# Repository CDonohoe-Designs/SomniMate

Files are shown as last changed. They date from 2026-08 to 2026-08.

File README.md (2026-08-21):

# SomniMate

**Pre-Obstructive Respiratory Signature Research Platform**

SomniMate is an engineering R&D project I am developing to investigate a specific question:

> **Can changes in thoracic and abdominal respiratory mechanics reveal a repeatable signature before an obstructive respiratory event?**

I am approaching the project as a hardware-first investigation. My priority is to acquire good respiratory data, understand the signal chain and test the hypothesis before making predictive claims.

The longer-term system concept is a connected wearable platform. SomniMate would act as the low-power sensing edge device, with a phone or PC client receiving data over BLE. A future mobile app could then provide the Internet gateway to an optional IoT backend for session storage, multi-night analysis and research dashboards. The app/cloud layer is intentionally deferred until the sensor chain and physiological value have been demonstrated.

> **Project status:** active research and development. The first custom RIP front-end Rev A has now progressed from hand calculation and LTspice verification into a completed Altium schematic with defined components, test points, output conditioning and filtered `3V3_AFE` supply. PCB development is the next hardware step.
>
> SomniMate is not a diagnostic medical device and is not intended for clinical use.

---

## Research concept

Thoracic and abdominal respiratory effort provide two related but independent views of breathing mechanics.

By measuring both channels together I want to investigate:

- respiratory effort amplitude
- breath-to-breath effort trends
- thorax-abdomen timing
- phase and coordination
- temporary respiratory discordance
- paradoxical movement
- waveform morphology
- changes occurring before, during and after respiratory events

I will use supporting signals such as PPG, movement, position, audio and ambient light as additional context rather than primary respiratory measurements.

I am not assuming that thoraco-abdominal paradox occurs before an obstructive event. The purpose of the project is to determine experimentally whether useful and repeatable pre-event changes are present.

---

## Development strategy

I am developing SomniMate as a staged engineering project. I first established the Nordic/Zephyr firmware and modular sensor platform, and I am now developing the respiratory-effort electronics separately so I can characterise the RIP measurement chain from first principles.

```mermaid
flowchart LR
    A["Prototype Firmware + Sensors"] --> B["Single-Channel RIP Oscillator Prototype"]
    B --> C["Characterise Respiratory Signal Chain"]
    C --> D["Dual-Channel Custom Hardware"]
    D --> E["SomniMate + SomniLink"]
    E --> F["Thorax-Abdomen Research"]
    F --> G["BLE App + IoT Integration"]
```

My immediate engineering goal is not a finished wearable or cloud platform. It is to establish a reliable single-channel respiratory-effort signal chain, understand its electrical and mechanical behaviour, and use measured results to drive the later integrated hardware.

---

## Firmware and sensor prototype

For the current development platform I am using:

- **Seeed nRF54L20A development board** — main controller and firmware platform
- **ADS1115 development board** — general analog acquisition and firmware development; no longer required in the primary RIP signal path
- **MAX30102 development board** — experimental PPG / heart-rate / SpO₂ channel
- **BH1750 development board** — ambient-light and recording-context channel
- IMU for movement and position
- microphone for acoustic / snoring investigation
- Zephyr firmware
- BLE / data logging

```mermaid
flowchart LR
    A["RIP Oscillator<br/>FREQ_OUT"] --> C["Seeed nRF54L20A<br/>Timer / Counter"]

    D["MAX30102<br/>PPG / HR"] --> C
    E["BH1750<br/>Ambient Light"] --> C
    F["IMU<br/>Motion / Position"] --> C
    G["Microphone<br/>Acoustic Context"] --> C

    C --> H["Zephyr Firmware"]
    H --> I["Sensor Acquisition"]
    H --> J["Timestamping"]
    H --> K["Signal Quality / Fault Handling"]

    I --> L["BLE / Local Data Logging"]
    J --> L
    K --> L
    L --> M["Mobile App / PC Client"]
    M --> N["Optional IoT Backend"]
    M --> O["Local Analysis"]
    N --> P["Multi-Night Analysis / Dashboard"]
```

I originally evaluated the ADS1115 as part of the respiratory acquisition path. After selecting a frequency-output RIP architecture, I no longer need an ADC in the primary RIP channel. The nRF54L20A can measure the oscillator frequency directly using a hardware timer/counter.

**[View the current firmware development](firmware/)**

---

## Custom RIP front-end prototype

For Rev A I selected a **discrete common-base Colpitts oscillator** so that RIP-belt inductance changes are represented directly as frequency changes.

The provisional model uses a 2 µH belt inductance, 2 Ω series-loss model and 1 nF / 1 nF Colpitts capacitive divider. I calculated a nominal resonance of approximately **5.03 MHz**; LTspice produced approximately **4.9 MHz** for the nominal case. Sweeping the assumed belt inductance from 1.5 µH to 2.5 µH produced approximately 5.6 MHz to 4.4 MHz, confirming the expected frequency sensitivity.

The oscillator simulation also showed that the raw resonant waveform requires conditioning before it reaches the Nordic MCU. I therefore added attenuation, Schottky limiting and a Schmitt-trigger stage to produce a clean **0–3.3 V `FREQ_RIP`** signal for direct timer/counter measurement.

The Altium Rev A schematic now implements the signal chain using an **MMBT3904LT1G** oscillator transistor, **BAT54SLT1G** Schottky clamp, **SN74LVC1G17DBVR** Schmitt buffer, a **47 Ω** series resistor on `FREQ_RIP`, explicit test points, and a filtered `3V3_AFE` rail. The AFE supply uses a simple **C-R-C / RC π-style filter** with 1 µF input capacitance, 10 Ω series isolation and 1 µF + 100 nF output decoupling, plus local 100 nF decoupling at the Schmitt buffer.

```mermaid
flowchart LR
    A["RIP Belt"] --> B["Colpitts LC Oscillator"]
    B --> C["Attenuation + Clamp Protection"]
    C --> D["Schmitt Buffer"]
    D --> E["FREQ_RIP"]
    E --> F["nRF54L20A<br/>Timer / Counter"]
```

**[View the RIP AFE design, calculations and LTspice verification →](hardware/SomniMate_RIP_AFE_Prototype/)**

---

## Intended dual-channel architecture

The later system is intended to contain two coordinated respiratory-effort modules:

- **SomniMate** — main controller and first respiratory-effort channel
- **SomniLink** — second respiratory-effort channel

```mermaid
flowchart LR
    A["Thoracic RIP Strap"] --> B["SomniMate<br/>RIP Oscillator"]
    C["Abdominal RIP Strap"] --> D["SomniLink<br/>RIP Oscillator"]

    D --> E["Inter-Module Link"]
    B --> F["SomniMate<br/>Main Controller"]
    E --> F

    G["PPG"] --> F
    H["IMU"] --> F
    I["Microphone"] --> F

    F --> J["Synchronized Acquisition"]
    J --> K["BLE / Logging"]
    J --> L["Signal Processing"]

    L --> M["Thorax-Abdomen<br/>Phase / Coordination"]
    L --> N["Breath-by-Breath<br/>Effort Features"]
    M --> O["Pre-Event Investigation"]
    N --> O
```

I have intentionally not fixed the eventual SomniLink-to-SomniMate interface yet. Synchronization, signal quality, size and power will drive that decision.

---

## Planned connected system architecture

SomniMate is intended to become the edge node of a connected monitoring platform without requiring Wi-Fi or cellular hardware in the wearable itself.

```mermaid
flowchart LR
    A["SomniMate + SomniLink<br/>Respiratory Sensing"] --> B["SomniMate<br/>nRF54 + Zephyr"]
    B -->|"BLE"| C["SomniMate Mobile App"]
    C -->|"Wi-Fi / Cellular"| D["Optional IoT Backend"]
    C --> E["Local Session Review"]
    D --> F["Session Storage"]
    D --> G["Multi-Night Trends"]
    D --> H["Research Dashboard"]
```

The intended division of responsibility is:

- **SomniMate wearable** — sensor acquisition, timestamping, signal-quality checks, local buffering and BLE communication.
- **Mobile app / PC client** — pairing, device status, recording control, data transfer, basic visualization and acting as the Internet gateway.
- **IoT backend** — optional later layer for synchronized session storage, multi-night analysis, algorithm development and remote research dashboards.

This keeps the body-worn hardware focused on sensing, synchronization and low-power BLE while allowing Internet connectivity to evolve independently. No app, cloud service or remote monitoring claim is part of the current hardware proof of concept.

**[View the connected IoT architecture →](docs/CONNECTED_IOT_ARCHITECTURE.md)**

---

## Wearable concept

My current mechanical concept uses separate thoracic and abdominal effort straps with a centrally mounted controller. It is an early development concept intended to explore sensor placement, cable routing and wearable integration rather than final industrial design.

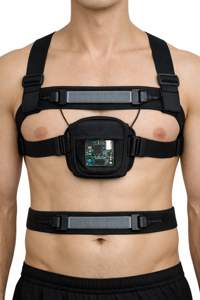
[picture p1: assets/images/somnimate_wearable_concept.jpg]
SomniMate wearable concept


**[View image in assets](assets/images/somnimate_wearable_concept.jpg)**

---

## Supporting sensors

### MAX30102

I am using the MAX30102 experimentally for:

- PPG waveform acquisition
- heart rate
- pulse amplitude changes
- experimental SpO₂ investigation

I am treating SpO₂ as experimental until the complete optical implementation and measurement method have been validated.

### IMU

I am using the IMU to investigate:

- body position
- posture changes
- movement detection
- motion artefacts

### Microphone

I am using the microphone experimentally for:

- snoring
- airway acoustic activity
- respiratory-event context

### BH1750

I added the BH1750 as a contextual sensor rather than a primary respiratory sensor. It can provide ambient-light level, lights-on / lights-off transitions and additional timestamped context during recordings while also giving me another useful I²C peripheral during firmware development.

---

## Development status

### Firmware and modular sensors

- [x] Core research question defined
- [x] Nordic / Zephyr environment established
- [x] Initial firmware bring-up
- [x] I²C communication established
- [x] ADS1115 evaluated
- [x] MAX30102 evaluated
- [x] Integrate ADS1115 and MAX30102 into common application
- [x] Add BH1750
- [x] Integrate IMU
- [x] Integrate microphone
- [ ] Implement synchronized timestamping
- [ ] Implement structured data logging
- [ ] Add RIP frequency measurement using Nordic timer/counter

### RIP front end

- [x] Create dedicated Altium RIP prototype project
- [x] Establish schematic / PCB / library / output project structure
- [x] Define Rev-A design criteria
- [x] Compare discrete and dedicated inductance-conversion architectures
- [x] Select discrete Colpitts oscillator for Rev A
- [x] Establish provisional 2 µH belt model
- [x] Calculate nominal LC resonance
- [x] Select and bias 3904-family oscillator device
- [x] Build LTspice oscillator model
- [x] Run RIP inductance sweep
- [x] Evaluate belt series-resistance / Q sensitivity
- [x] Add attenuation and Schmitt-trigger output conditioning
- [x] Verify clean 0–3.3 V `FREQ_RIP` output in LTspice
- [x] Add and simulate `3V3_AFE` RC π-style supply filter
- [x] Select real Rev A parts for Q1, D1 and U1
- [x] Add prototype test points
- [x] Complete the Rev A Altium schematic
- [x] Generate the Rev A schematic PDF output
- [ ] Design the prototype PCB
- [ ] Assemble and bring up the prototype
- [ ] Characterise actual belt inductance / sensitivity / losses
- [ ] Capture controlled respiratory waveforms

### Dual-channel SomniMate / SomniLink hardware

- [ ] Convert measured single-channel results into the dual-channel architecture
- [ ] Design SomniMate controller hardware
- [ ] Design SomniLink hardware
- [ ] Define inter-module communication
- [ ] Build and bring up custom PCBs
- [ ] Verify synchronized thoracic / abdominal operation
- [ ] Evaluate wearable implementation
- [ ] Begin overnight dual-channel data collection
- [ ] Perform thoraco-abdominal phase / coordination analysis

### Connected app / IoT layer — later phase

- [ ] Define BLE GATT services and structured session-data format
- [ ] Prototype SomniMate mobile app or PC client
- [ ] Implement device status, recording control and data transfer over BLE
- [ ] Define secure app-to-backend session upload
- [ ] Prototype optional IoT session storage
- [ ] Add multi-night trend and research-dashboard capability

---

**SomniMate is an independent research and engineering project. It is not a diagnostic or therapeutic medical device.**

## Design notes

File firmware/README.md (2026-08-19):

# Firmware Development

This folder contains the staged Zephyr / nRF Connect SDK bring-up work used during Phase 1 of SomniMate.

The examples are intentionally kept small so that each interface can be verified independently before moving to the next stage.

## Bring-up sequence

1. **01_ADS1115_Bringup** — basic I²C communication with the ADS1115 and configuration-register readback.
2. **02_MAX30102_Bringup** — basic I²C communication with the MAX30102 and Part ID verification.
3. **03_ADS1115_MAX30102** — confirms that the ADS1115 and MAX30102 operate together on the same I²C bus.
4. **04_ADS1115_Potentiometer** — configures ADS1115 AIN3 for single-ended conversion and verifies analogue voltage measurement using a potentiometer.
5. **05_BH1750_Bringup** — reads ambient-light level from a GY-302 / BH1750 sensor in continuous high-resolution mode.
6. **06_ADS1115_MAX30102_BH1750** — confirms that the ADS1115, MAX30102 and BH1750 can operate together on the same I²C bus.

Current bring-up platform: **Nordic nRF5340 DK** with **Zephyr / nRF Connect SDK**.

The nRF5340 DK is being used as the initial firmware-learning and sensor-integration platform before moving the prototype to the planned nRF54L20A hardware.

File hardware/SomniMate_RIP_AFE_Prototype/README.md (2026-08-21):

# SomniMate RIP AFE Prototype

**Rev A — Discrete Colpitts respiratory-inductance front end**

This folder is the engineering record for the first custom SomniMate respiratory inductance plethysmography (RIP) front end.

I am using a hardware-first approach: define the sensing requirement, calculate a starting circuit, verify it in LTspice, document the assumptions and then carry the verified design into Altium for PCB development.

> **Status:** Rev A oscillator, output conditioning and `3V3_AFE` supply filtering have been verified in LTspice and transferred into a completed Altium schematic. PCB development is the next step.
>
> This is a non-clinical R&D prototype, not a diagnostic or therapeutic medical device.

---

## Design objective

For Rev A I am deliberately developing **one RIP channel** before duplicating the architecture for synchronized thoracic and abdominal measurements.

My design priorities are:

- small physical size
- low power consumption
- 3.3 V operation
- low component count and BOM cost
- direct interface to an nRF54L20A timer/counter
- relative respiratory-effort measurement rather than calibrated lung-volume measurement
- simple duplication for a second channel
- testability and accessible signal nodes
- tolerance of belt-to-belt electrical variation
- low-voltage battery-powered wearable operation

The current signal chain is:

```mermaid
flowchart LR
    A["RIP Belt"] --> B["Colpitts LC Oscillator"]
    B --> C["Attenuation + Clamp Protection"]
    C --> D["Schmitt Buffer"]
    D --> E["FREQ_RIP"]
    E --> F["nRF54L20A Timer / Counter"]
    F --> G["Relative Respiratory Effort"]
```

I chose a frequency-output architecture rather than producing an analog respiratory voltage. This removes the need for an ADC, conventional anti-alias filter and unity-gain op-amp buffer in the primary RIP path.

---

## Architecture choice

I considered four approaches:

1. discrete LC oscillator with MCU frequency measurement
2. dedicated inductance-to-digital conversion, including the TI LDC1612
3. oscillator followed by frequency-to-voltage conversion and ADC
4. synchronous analog excitation/demodulation

For Rev A I selected a **common-base Colpitts oscillator**.

I chose the discrete approach because it keeps the sensing mechanism visible, is compact and low power, and gives me direct control over excitation, loading and output conditioning. It also lets me characterize the unknown RIP-belt electrical behaviour before considering a more integrated converter.

The TI LDC1612 remains a credible later alternative, particularly because one device could potentially support two inductive channels.

---

## Rev A starting model

I do not yet have measured LCR data for the physical RIP belt, so the belt values below are explicitly **provisional modelling assumptions**.

| Parameter | Rev A value |
|---|---:|
| Supply | 3.3 V |
| Q1 hardware | MMBT3904LT1G |
| R1 | 47 kΩ |
| R2 | 18 kΩ |
| R3 | 470 Ω |
| Belt series resistance model | 2 Ω nominal |
| RIP inductance | 2 µH nominal |
| Inductance sweep | 1.5–2.5 µH |
| C1 | 1 nF |
| C2 | 1 nF |
| C3 | 100 nF |
| C4 | 10 nF |
| Output divider R5/R6 | 10 kΩ / 10 kΩ |
| Output clamp | BAT54SLT1G |
| Schmitt buffer | SN74LVC1G17DBVR |
| Output series resistor R7 | 47 Ω |
| Supply filter | 1 µF / 10 Ω / 1 µF + 100 nF |
| U1 local decoupling | 100 nF |

For the Colpitts divider:

```text
Ceq = (C1 × C2) / (C1 + C2)
    = (1 nF × 1 nF) / (1 nF + 1 nF)
    = 500 pF
```

Using the provisional 2 µH belt value:

```text
f0 = 1 / (2π√(LC))
   ≈ 5.03 MHz
```

This was my first-order design target before simulation.

---

## LTspice verification

### 1. Oscillator implementation

I built the Rev A common-base Colpitts model in LTspice and annotated the circuit with the assumptions and key design intent.

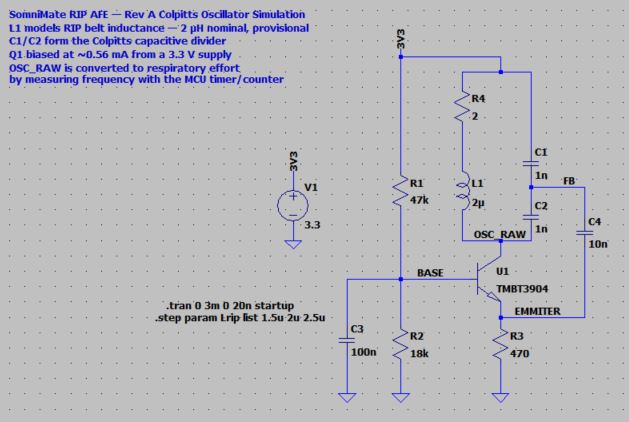
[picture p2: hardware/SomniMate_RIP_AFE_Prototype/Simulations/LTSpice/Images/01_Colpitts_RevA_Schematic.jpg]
Rev A Colpitts schematic


### 2. RIP inductance sensitivity

I swept the provisional RIP-belt inductance using:

```text
.step param Lrip list 1.5u 2u 2.5u
```

The result confirms the expected monotonic relationship: increasing inductance lowers the oscillator frequency.

| Assumed RIP inductance | Ideal calculation | Approx. LTspice result |
|---:|---:|---:|
| 1.5 µH | 5.81 MHz | ~5.6 MHz |
| 2.0 µH | 5.03 MHz | ~4.9 MHz |
| 2.5 µH | 4.50 MHz | ~4.4 MHz |

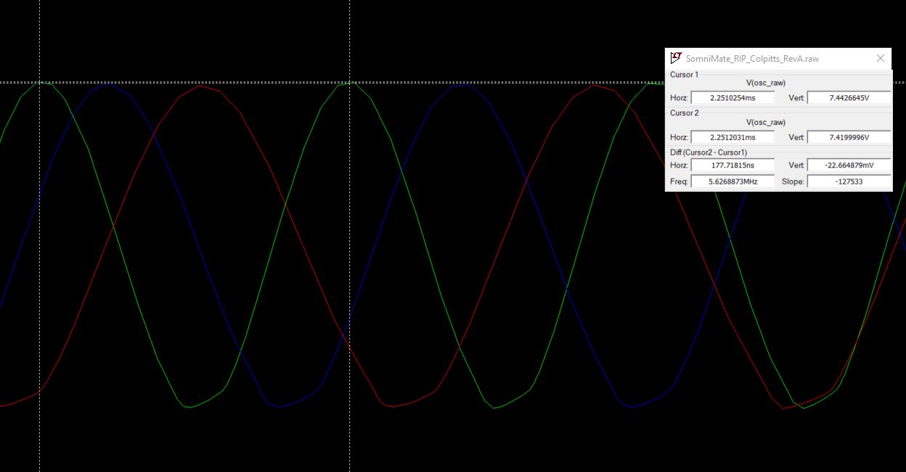
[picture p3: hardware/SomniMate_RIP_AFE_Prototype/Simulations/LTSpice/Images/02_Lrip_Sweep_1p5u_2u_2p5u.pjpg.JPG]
RIP inductance sweep


The small difference between the ideal calculation and simulated result is expected because the hand calculation treats the tank as ideal while the LTspice circuit includes transistor loading and parasitic behaviour.

### 3. Bias and power

The LTspice operating-point analysis gave approximately:

- base voltage: **0.864 V**
- emitter voltage: **0.263 V**
- emitter current: **0.559 mA**
- total supply current: **0.607 mA**

At 3.3 V this corresponds to approximately:

```text
P ≈ 3.3 V × 0.607 mA ≈ 2.0 mW
```

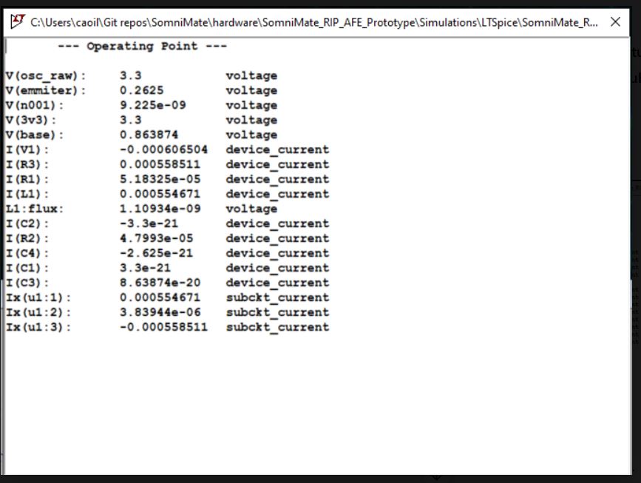
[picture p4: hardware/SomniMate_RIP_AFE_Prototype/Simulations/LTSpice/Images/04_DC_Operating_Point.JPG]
DC operating point


This is a useful first-pass result for a battery-powered wearable sensor channel. I have not yet attempted to optimize the oscillator below this current.

### 4. Belt-loss / Q sensitivity

A real RIP belt is not an ideal inductor. I therefore added a series-resistance model and investigated increasing resonator loss.

The current Rev A topology has strong oscillation margin around the provisional **2 Ω** case, while 5–10 Ω produces substantially reduced amplitude.

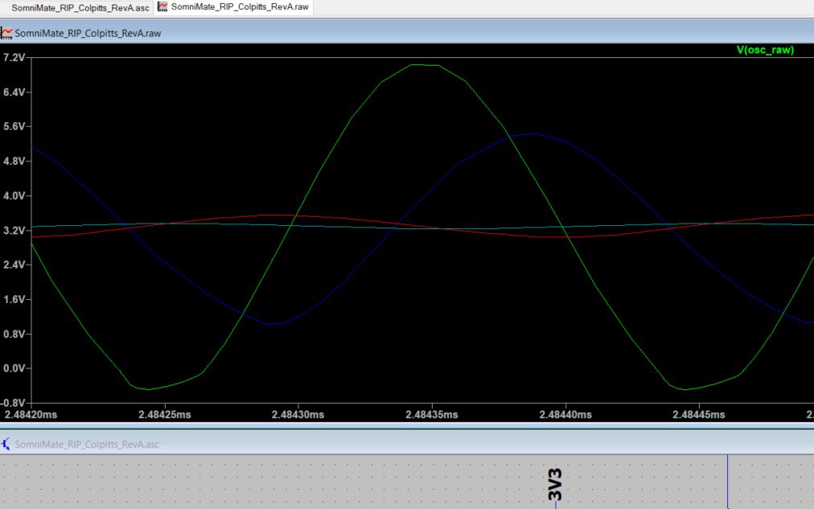
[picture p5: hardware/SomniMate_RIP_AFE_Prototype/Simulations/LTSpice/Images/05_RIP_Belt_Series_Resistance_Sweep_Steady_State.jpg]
RIP belt series resistance sweep


---

## Output conditioning

The oscillator simulation also exposed an important interface requirement: the raw resonant waveform is not a safe MCU logic signal.

I therefore added:

- a **10 kΩ / 10 kΩ divider** to attenuate `OSC_RAW`
- a **BAT54SLT1G dual Schottky clamp** around the buffer input
- an **SN74LVC1G17DBVR Schmitt-trigger buffer** to convert the sine-like waveform into a clean 0–3.3 V digital signal
- a **47 Ω series resistor** on `FREQ_RIP`

The LTspice model uses the generic behavioral `schmtbuf` device to verify the transfer concept; the Altium implementation uses the selected hardware part.

### Final attenuated, protected and buffered Rev A schematic

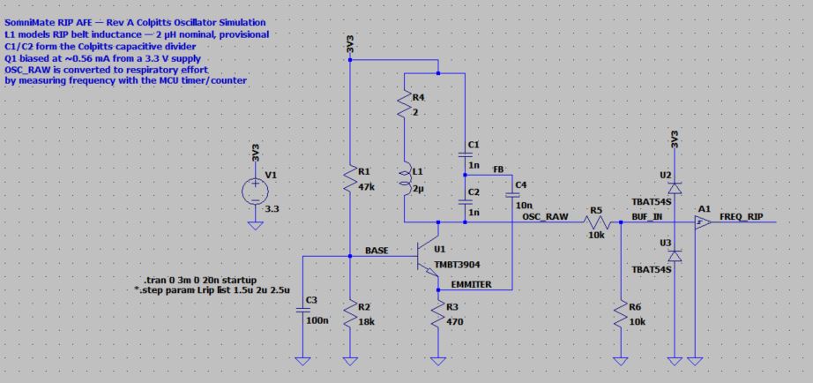
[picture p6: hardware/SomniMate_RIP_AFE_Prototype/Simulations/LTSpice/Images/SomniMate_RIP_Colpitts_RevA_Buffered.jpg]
Buffered Rev A Colpitts schematic


### Raw oscillator waveform

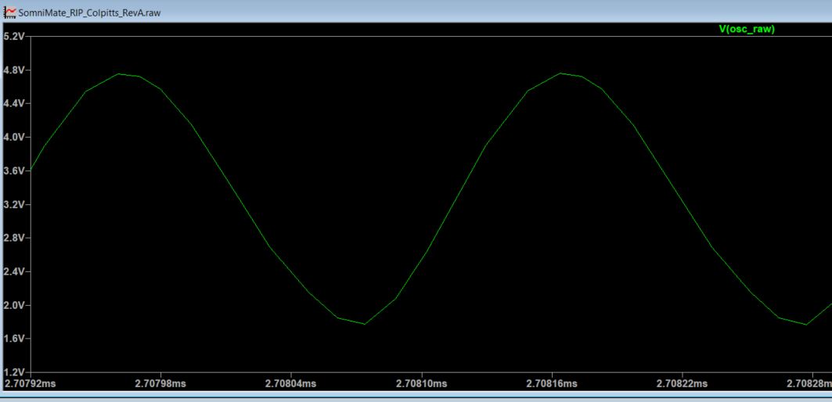
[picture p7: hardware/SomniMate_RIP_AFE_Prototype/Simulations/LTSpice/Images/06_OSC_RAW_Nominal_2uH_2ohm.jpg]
OSC RAW


### Attenuated / protected buffer input

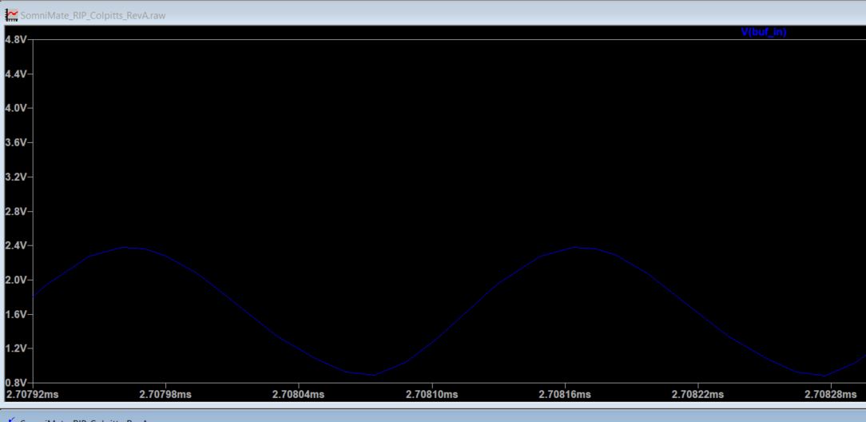
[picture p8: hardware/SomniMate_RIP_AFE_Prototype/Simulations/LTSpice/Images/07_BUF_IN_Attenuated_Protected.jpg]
Buffer input


### Schmitt output

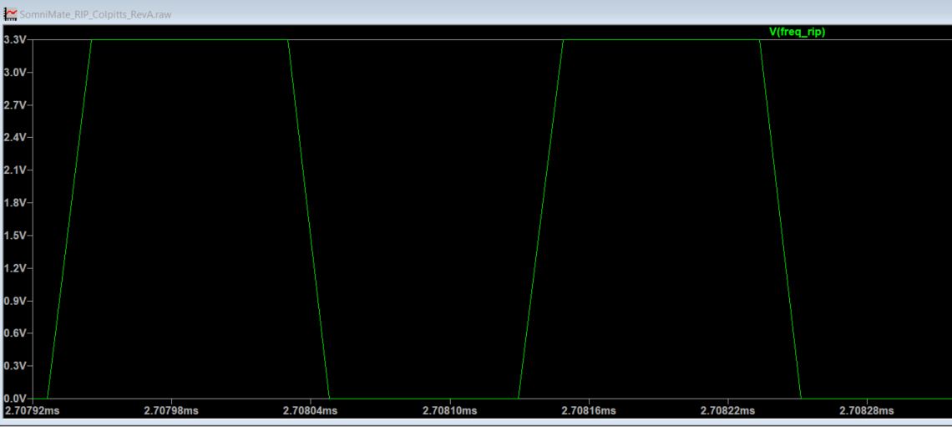
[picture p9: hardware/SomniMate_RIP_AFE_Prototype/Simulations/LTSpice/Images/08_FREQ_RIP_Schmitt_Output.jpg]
FREQ RIP


### Complete signal conversion

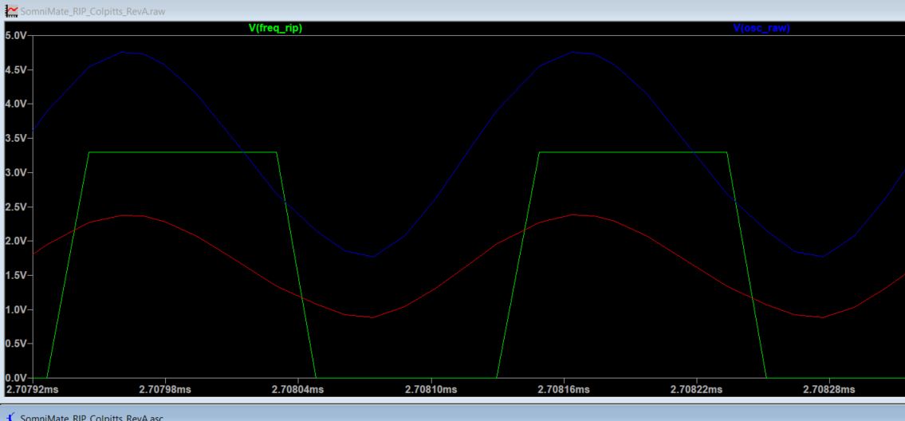
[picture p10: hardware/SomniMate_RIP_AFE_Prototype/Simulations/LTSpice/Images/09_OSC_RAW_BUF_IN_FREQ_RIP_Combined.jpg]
OSC RAW, BUF IN and FREQ RIP


---

## 3V3_AFE supply filtering

I added a simple **C-R-C / RC π-style supply filter** between the main 3.3 V rail and the sensitive RIP AFE supply.

The implemented network is:

```text
3V3 ----+---- R8 10Ω ----+---- 3V3_AFE
        |                |
      C5 1µF           C6 1µF
        |                |
       GND             C7 100nF
                         |
                        GND
```

C6 and C7 are electrically in parallel. A separate **C8 = 100 nF** is placed locally at the SN74LVC1G17 supply pins.

The purpose is to reduce supply-borne digital noise reaching the oscillator and to provide impedance isolation between the AFE and the main 3.3 V rail. It is not galvanic isolation.

I modelled the filter separately in LTspice using a simplified 0.5 Ω source/interconnect impedance and an AC sweep from 10 Hz to 500 MHz.

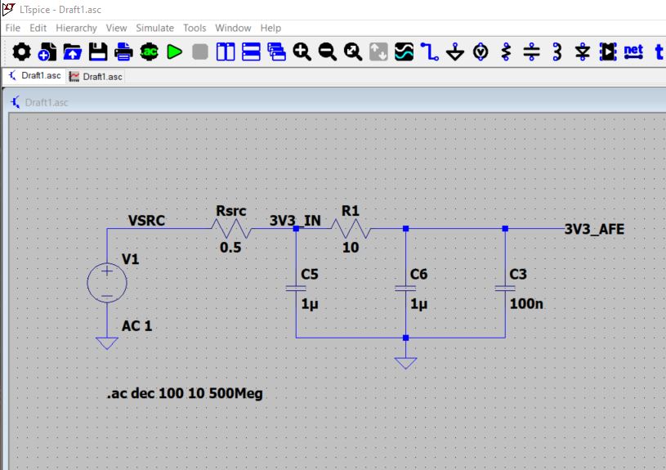
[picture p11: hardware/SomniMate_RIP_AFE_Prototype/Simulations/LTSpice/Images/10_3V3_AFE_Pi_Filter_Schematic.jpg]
3V3 AFE pi-style filter schematic


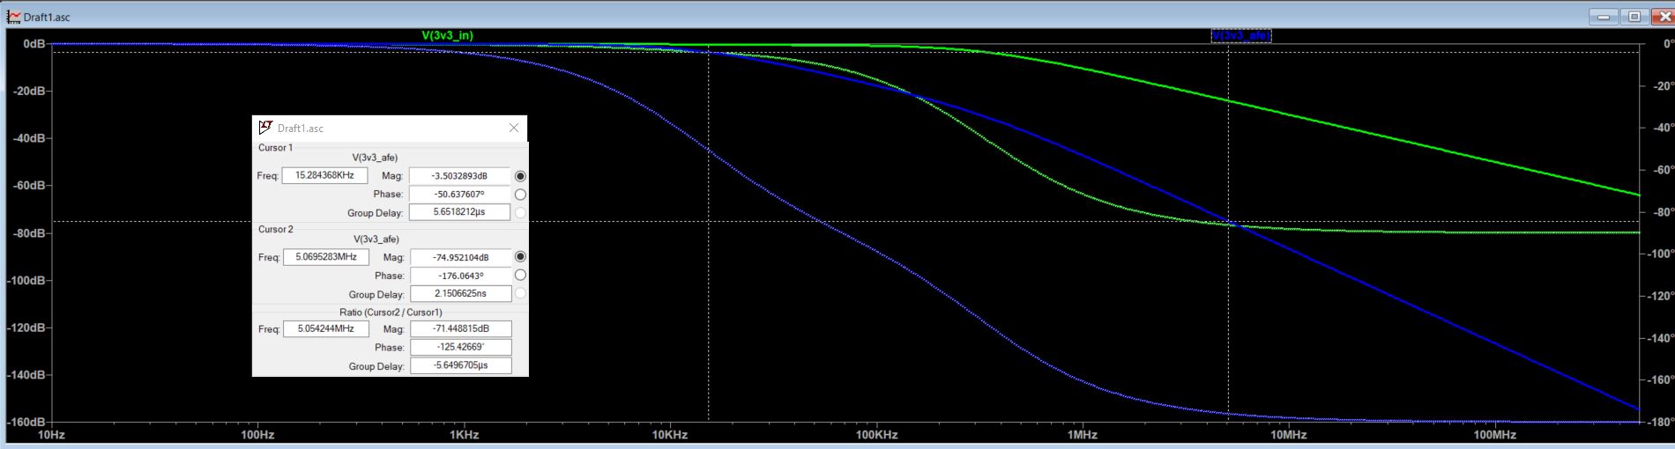
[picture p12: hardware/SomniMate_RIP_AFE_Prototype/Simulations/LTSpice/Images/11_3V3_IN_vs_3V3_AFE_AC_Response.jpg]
3V3 input versus filtered AFE rail


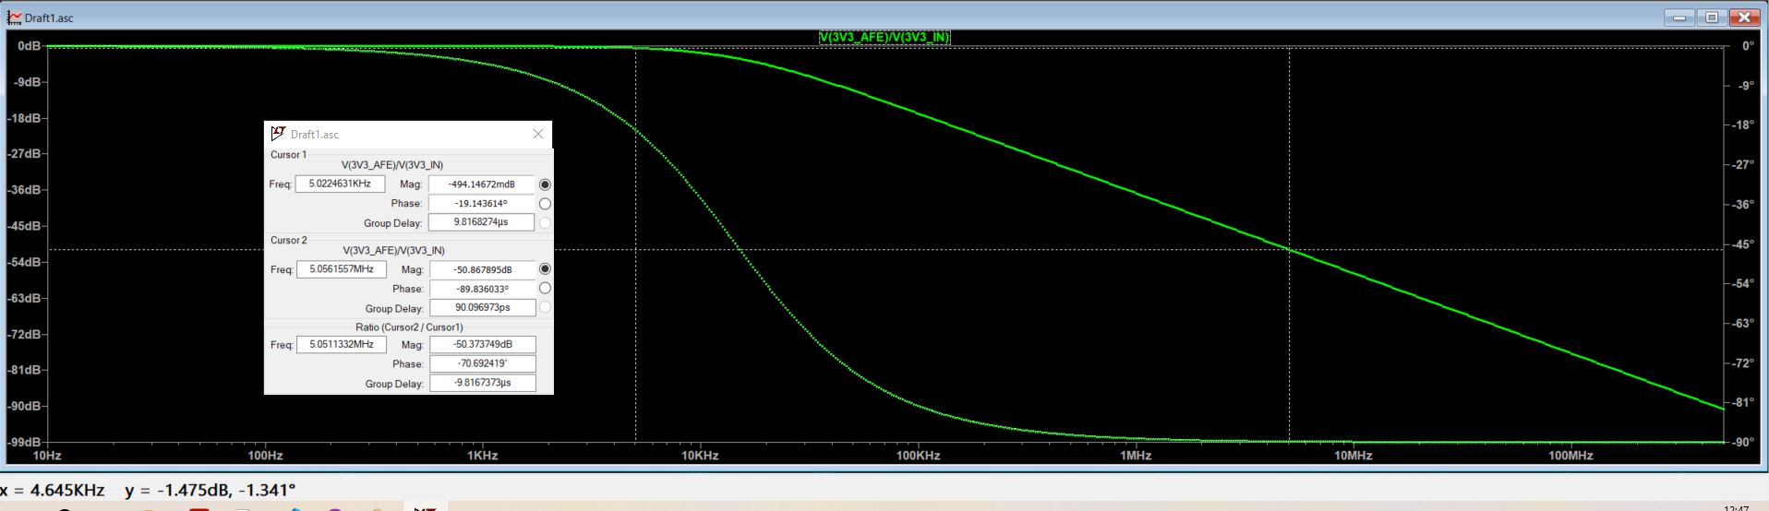
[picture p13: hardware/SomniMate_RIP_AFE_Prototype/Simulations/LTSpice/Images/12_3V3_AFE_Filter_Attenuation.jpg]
3V3 AFE filter attenuation


The simplified transfer model shows approximately **-50.9 dB attenuation at 5.06 MHz** for `V(3V3_AFE)/V(3V3_IN)`. This is a useful architecture-level result because the nominal RIP oscillator operates near 5 MHz, but it should not be treated as measured PCB performance. Real capacitor ESR, ESL, package parasitics and layout will alter the high-frequency response.

**[View the detailed supply-filter study →](Simulations/LTSpice/3V3_AFE_SUPPLY_FILTER.md)**

---

## Rev A Altium schematic

The verified LTspice architecture has now been transferred into a complete Altium schematic titled:

**SomniLink — Respiratory Inductance Plethysmography (RIP) Analog Front End — Rev A**

Drawing number: **SM-RIP-AFE-001**  
Revision: **A**

The schematic includes:

- selected real components for Q1, D1 and U1
- `OSC_RAW`, `BUF_IN` and `FREQ_RIP` signal labels
- `3V3_AFE` filtered supply rail
- explicit supply and signal test points
- provisional external RIP-belt assumption note
- local decoupling
- drawing title, revision, author and project identification

J1 remains a schematic-level generic two-pin RIP belt interface because the final physical strap termination / snap implementation has not yet been selected.

**[View the Rev A schematic PDF →](Outputs/SomniLink_RIP_AFE_RevA_Schematic.pdf)**

---

## Engineering conclusions from Rev A

The work to date has established enough confidence to proceed into PCB development:

- the discrete Colpitts architecture starts and sustains oscillation with the provisional RIP model
- the calculated and simulated nominal frequencies are in close agreement
- frequency responds strongly to the assumed RIP inductance range
- the oscillator operates at approximately 0.61 mA / 2 mW in the current bias configuration
- real belt series resistance / resonator Q will materially affect oscillator margin
- the raw resonant node can exceed normal MCU input levels
- attenuation, limiting and Schmitt edge conditioning provide a practical digital `FREQ_RIP` interface
- the nRF54L20A can therefore measure respiratory information as frequency rather than ADC voltage
- supply filtering has been added to reduce coupling from the main digital 3.3 V rail into the RIP AFE
- the complete Rev A circuit is now captured in Altium with test points and selected physical components

---

## Medical-device-aware design considerations

Although this is not being developed as a medical-grade device, I am keeping relevant product-development principles in mind:

- low-voltage, battery-powered body-worn operation
- low excitation energy
- component derating
- fault detectability for belt open/short or oscillator failure
- explicit test points and design verification
- defined assumptions rather than unsupported clinical claims
- EMC awareness around a MHz-range oscillator and external belt conductors
- separation between engineering prototype verification and formal medical-device safety/regulatory work

Formal patient safety, regulatory classification and IEC 60601 compliance are outside the scope of this Rev A prototype and would require specialist review in a medical-device development programme.

---

## Project files

```text
SomniMate_RIP_AFE_Prototype/
├── Schematic/
│   └── RIP_AFE.SchDoc
├── Outputs/
│   └── SomniLink_RIP_AFE_RevA_Schematic.pdf
├── Simulations/
│   └── LTSpice/
│       ├── SomniMate_RIP_Colpitts_RevA.asc
│       ├── SomniMate_RIP_Colpitts_RevA_Buffered.asc
│       ├── SomniMate_RIP_AFE_3V3_Pi_Filter.asc
│       ├── 3V3_AFE_SUPPLY_FILTER.md
│       └── Images/
├── Libraries/
├── SomniMate_RIP_AFE_Prototype.OutJob
├── README.md
└── SomniMate_RIP_AFE_Prototype.PrjPcb
```

---

## Next step

The next engineering step is **PCB design** for the Rev A RIP AFE.

Physical belt characterization will then replace the provisional 2 µH / 2 Ω model with measured values and determine whether Rev A needs to be retuned before dual-channel development.

---

**SomniMate is an independent research and engineering project. It is not a diagnostic or therapeutic medical device.**

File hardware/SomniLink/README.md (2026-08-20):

# SomniLink Hardware

Second respiratory-effort module, including its RIP front end, local measurement circuitry, power and link to SomniMate.

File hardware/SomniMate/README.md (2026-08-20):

# SomniMate Hardware

Main controller hardware, first respiratory-effort channel, supporting sensors, power and communications.

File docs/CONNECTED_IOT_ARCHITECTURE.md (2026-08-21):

# SomniMate Connected IoT Architecture

SomniMate is being developed as a **connected wearable respiratory R&D platform**. I am treating the system as more than a sensor board: the intended data path runs from body-worn sensing, through embedded processing and BLE, to a mobile companion and optionally onward to cloud-connected storage and analysis.

> **Project status:** the wearable hardware and firmware are being developed first. The mobile and cloud layers below describe the target connected-system architecture and should not be interpreted as completed product features.

```mermaid
flowchart LR
    A[Thorax RIP belt] --> B[SomniLink RIP AFE]
    C[Abdomen RIP belt] --> D[Second RIP channel]
    B --> E[SomniMate\nnRF54L20A + Zephyr]
    D --> E
    E -->|BLE| F[Mobile companion]
    F -->|Secure network connection| G[Cloud-connected data store / analysis]
    G --> H[Multi-night signal review\nand research analysis]
```

## System partitioning

### SomniLink / sensing hardware

The sensor-side electronics convert changes in RIP-belt inductance into a frequency-domain signal suitable for direct timer/counter measurement by the MCU. The current Rev A design uses a discrete Colpitts oscillator, attenuation and Schottky protection, followed by a Schmitt-trigger buffer.

### SomniMate / edge device

The main wearable controller is based around the Nordic nRF54L20A and Zephyr. Its role is to acquire respiratory signals, timestamp and condition the data, perform appropriate edge processing, manage the wearable state and expose the data over BLE.

### Mobile companion

The intended mobile layer provides the BLE gateway, device configuration, session control and local visualisation. It also provides the natural bridge between the low-power wearable and internet-connected services.

### Cloud-connected analysis

A later cloud layer can provide session storage, multi-night comparison and offline analysis of respiratory patterns. This is an R&D data-analysis architecture rather than a claim of clinical diagnosis or validated medical monitoring.

## Why use BLE rather than connecting the wearable directly to the cloud?

BLE keeps the body-worn electronics small and low power. The phone already provides a display, user interface, internet connection and significantly larger energy budget. This allows SomniMate to remain a low-power sensing and edge-processing device while still participating in a wider connected IoT system.

## Design intent

I am using the project to demonstrate the complete engineering chain rather than treating each PCB as an isolated design:

**sensor physics → analogue/front-end electronics → embedded acquisition → BLE → mobile gateway → connected data analysis**

The mobile and cloud layers will remain clearly marked as planned until they are implemented and demonstrated.

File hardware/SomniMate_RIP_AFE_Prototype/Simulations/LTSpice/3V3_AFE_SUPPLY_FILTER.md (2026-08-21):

# SomniMate RIP AFE — 3V3 Supply Filter Study

## Purpose

I added a simple **C-R-C supply filter** between the main SomniMate 3.3 V rail and the RIP analogue/front-end supply. The aim is to reduce supply-borne noise from the MCU, BLE activity and other digital circuitry before it reaches the Colpitts oscillator and its output-conditioning stage.

This is an **RC pi-style filter**, not an LC filter. The series element is deliberately a resistor because the RIP AFE current is low and the approach is simple, predictable and easy to prototype.

## Rev A network

```text
                         R8 10R
3V3_IN  -----+----------/\/\/\----------+----- 3V3_AFE
             |                          |
           C5 1uF                    C6 1uF
             |                          |
            GND                       GND
                                        |
                                     C7 100nF
                                        |
                                       GND
```

C6 and C7 are electrically in parallel on the `3V3_AFE` rail. The 100 nF capacitor is retained as a high-frequency local bypass even though an ideal-capacitor AC model shows little difference compared with the 1 uF capacitor alone. In hardware, capacitor ESR, ESL and self-resonant frequency matter.

A separate **100 nF local decoupling capacitor** is also placed directly at the SN74LVC1G17 VCC pin.

## LTspice model

For the standalone AC study I used:

| Element | Value | Purpose |
|---|---:|---|
| Source | AC 1 | Small-signal AC stimulus |
| Rsrc | 0.5 ohm | Simple source/interconnect impedance model |
| C5 | 1 uF | Input-side shunt capacitor |
| R8 | 10 ohm | Series isolation resistor |
| C6 | 1 uF | Output-side bulk/local capacitor |
| C7 | 100 nF | Higher-frequency bypass capacitor |

AC sweep:

```text
.ac dec 100 10 500Meg
```

The source impedance and capacitors are intentionally simplified first-pass models; the results are therefore useful for architecture verification rather than a claim of exact PCB performance.

## Results

The node-to-node AC response shows the filtered `3V3_AFE` rail rolling off while the input rail remains comparatively unchanged. In the current idealised model, the filtered node is approximately **-3.5 dB at 15.3 kHz** relative to the AC stimulus and approximately **-75 dB at 5.07 MHz**.

More usefully, the transfer ratio `V(3V3_AFE)/V(3V3_IN)` shows approximately **-50.9 dB attenuation at 5.06 MHz**. This is particularly relevant because the nominal RIP oscillator operates at approximately 5 MHz.

These values should be treated as simulation results for the simplified network, not measured hardware performance.

## Evidence

3V3 AFE pi-style filter schematic

3V3 input versus filtered AFE rail

3V3 AFE filter attenuation

## Design decision

I am carrying the filter into the Rev A Altium schematic as:

- `C5 = 1 uF`
- `R8 = 10 ohm`
- `C6 = 1 uF`
- `C7 = 100 nF`
- `C8 = 100 nF` local decoupling at the SN74LVC1G17

The next level of simulation, if required, would use real capacitor ESR/ESL or manufacturer models to examine high-frequency decoupling behaviour more realistically.

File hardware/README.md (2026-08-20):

# Hardware

Public-facing hardware development for SomniMate.

- `Common/RIP_AFE` — reusable respiratory inductance plethysmography analog front end used by both modules.
- `SomniMate` — main controller hardware and first respiratory-effort channel.
- `SomniLink` — second respiratory-effort module and link to SomniMate.

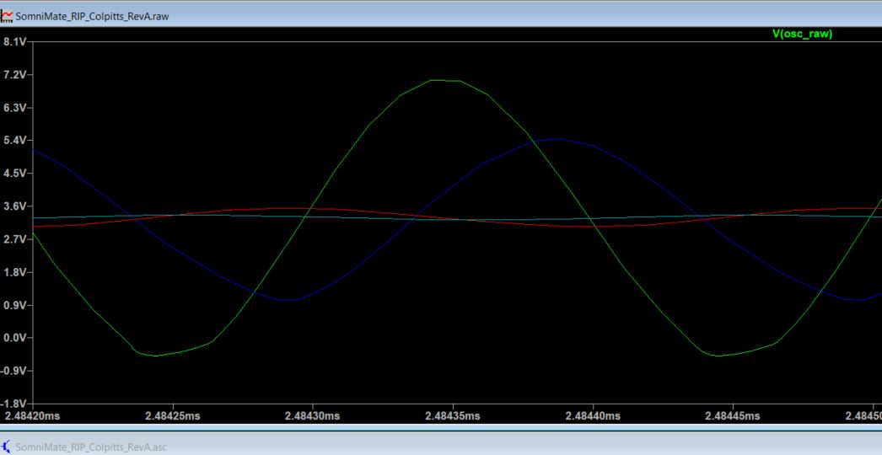
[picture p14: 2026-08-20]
hardware/SomniMate_RIP_AFE_Prototype/Simulations/LTSpice/Images/05_RIP_Belt_Series_Resistance_Sweep.JPG

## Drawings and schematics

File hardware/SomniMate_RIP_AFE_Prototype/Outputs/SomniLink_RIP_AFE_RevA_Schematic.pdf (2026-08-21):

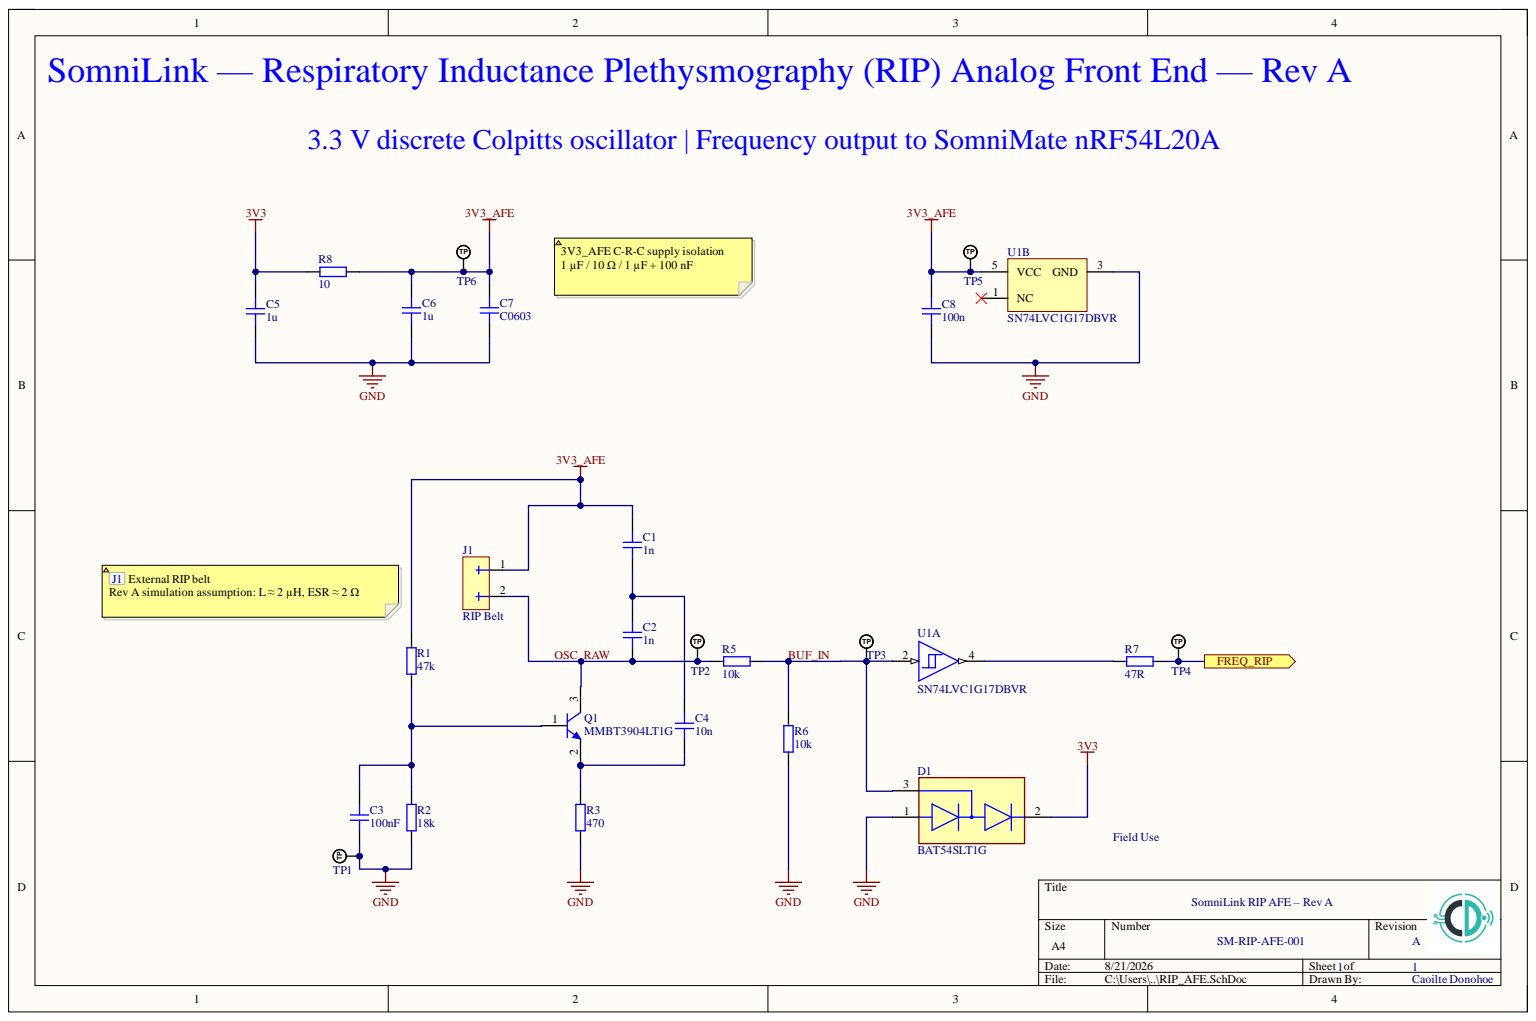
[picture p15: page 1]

SomniLink — Respiratory Inductance Plethysmography (RIP) Analog Front End — Rev A

3.3 V discrete Colpitts oscillator | Frequency output to SomniMate nRF54L20A

J1 External RIP belt
Rev A simulation assumption: L ≈ 2 µH, ESR ≈ 2 Ω

SomniLink RIP AFE – Rev A

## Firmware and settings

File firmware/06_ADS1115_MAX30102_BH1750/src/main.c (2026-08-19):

/*
 * Project: nRF5340 Zephyr Sensor Bring-Up
 * File: main.c
 * Author: Caoilte Donohoe
 *
 * Purpose:
 * Combined I2C bring-up test for the ADS1115, MAX30102 and BH1750.
 * Confirms that all three devices can operate on the same I2C bus
 * using separate device addresses.
 *
 * Hardware:
 * - Nordic nRF5340 DK
 * - ADS1115 ADC
 * - MAX30102 optical sensor
 * - GY-302 / BH1750 ambient-light sensor
 *
 * Framework:
 * - Zephyr RTOS
 * - nRF Connect SDK
 */
#include <stdio.h>
#include <stdint.h>
#include <zephyr/kernel.h>
#include <zephyr/drivers/i2c.h>

int main(void)
{
    uint8_t max30102_address = 0x57;
    uint8_t max30102_part_id_reg = 0xFF;
    uint8_t max30102_part_id;

    uint8_t ads1115_address = 0x48;
    uint8_t ads1115_config_reg = 0x01;
    uint8_t ads1115_conf_bytes[2];

    uint8_t bh1750_address = 0x23;
    uint8_t bh1750_mode = 0x10;
    uint8_t bh1750_data[2];
    uint16_t raw_light;
    uint32_t lux_x10;

    const struct device *i2c_dev =
        DEVICE_DT_GET(DT_NODELABEL(arduino_i2c));

    printf("Board: %s\n", CONFIG_BOARD_TARGET);

    if (!device_is_ready(i2c_dev))
    {
        printf("I2C device is not ready\n");
        return -1;
    }

    printf("I2C device is ready\n\n");

    /* BH1750 */
    i2c_write(
        i2c_dev,
        &bh1750_mode,
        1,
        bh1750_address);

    printf("BH1750 initialized\n");

    k_msleep(180);

    i2c_read(
        i2c_dev,
        bh1750_data,
        2,
        bh1750_address);

    raw_light =
        (bh1750_data[0] << 8) |
         bh1750_data[1];

    lux_x10 = ((uint32_t)raw_light * 10) / 12;

    printf("BH1750 Light = %u.%u lux\n",
           lux_x10 / 10,
           lux_x10 % 10);

    /* MAX30102 */
    printf("MAX30102 address: 0x%x\n", max30102_address);

    int result_MAX30102 = i2c_write_read(
        i2c_dev,
        max30102_address,
        &max30102_part_id_reg,
        1,
        &max30102_part_id,
        1);

    printf("MAX30102 I2C result: %d\n", result_MAX30102);
    printf("MAX30102 Part ID: 0x%x\n", max30102_part_id);

    if (max30102_part_id == 0x15)
    {
        printf("MAX30102 detected\n");
    }

    printf("\n");

    /* ADS1115 */
    printf("ADS1115 address: 0x%x\n", ads1115_address);

    int result_ADS1115 = i2c_write_read(
        i2c_dev,
        ads1115_address,
        &ads1115_config_reg,
        1,
        ads1115_conf_bytes,
        2);

    printf("ADS1115 I2C result: %d\n", result_ADS1115);

    printf("ADS1115 Config: 0x%02x%02x\n",
           ads1115_conf_bytes[0],
           ads1115_conf_bytes[1]);

    return 0;
}

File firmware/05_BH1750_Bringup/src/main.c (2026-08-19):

/*
 * Project: nRF5340 Zephyr Sensor Bring-Up
 * File: main.c
 * Author: Caoilte Donohoe
 *
 * Purpose:
 * Basic I2C bring-up test for the BH1750 ambient-light sensor.
 * Configures continuous high-resolution measurement mode and
 * prints light level in lux.
 *
 * Hardware:
 * - Nordic nRF5340 DK
 * - GY-302 / BH1750 ambient-light sensor
 *
 * Framework:
 * - Zephyr RTOS
 * - nRF Connect SDK
 */
#include <stdio.h>
#include <stdint.h>
#include <zephyr/kernel.h>
#include <zephyr/drivers/i2c.h>

int main(void)
{
    uint8_t bh1750_address = 0x23;
    uint8_t bh1750_mode = 0x10;

    uint8_t bh1750_data[2];
    uint16_t raw_light;
    uint32_t lux_x10;

    const struct device *i2c_dev =
        DEVICE_DT_GET(DT_NODELABEL(arduino_i2c));

    printf("BH1750 Address: 0x%x\n", bh1750_address);
    printf("Board: %s\n", CONFIG_BOARD_TARGET);

    if (!device_is_ready(i2c_dev))
    {
        printf("I2C device is not ready\n");
        return -1;
    }

    printf("I2C device is ready\n");

    /* Continuous High Resolution Mode */
    i2c_write(
        i2c_dev,
        &bh1750_mode,
        1,
        bh1750_address);

    /* Allow first measurement to complete */
    k_msleep(180);

    while (1)
    {
        i2c_read(
            i2c_dev,
            bh1750_data,
            2,
            bh1750_address);

        raw_light =
            (bh1750_data[0] << 8) |
             bh1750_data[1];

        /* BH1750 conversion: lux = raw / 1.2 */
        lux_x10 = ((uint32_t)raw_light * 10) / 12;

        printf("Light = %u.%u lux\n",
               lux_x10 / 10,
               lux_x10 % 10);

        k_msleep(500);
    }

    return 0;
}

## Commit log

2026-08-19 Create SomniMate public landing README
2026-08-19 Revise README around research and embedded prototype architecture
2026-08-19 Replace BreathPal phase with nRF54L20A prototype
2026-08-19 Restructure development into prototype and custom hardware phases
2026-08-19 Add combined ADS1115 and MAX30102 I2C bring-up firmware
2026-08-19 Add ADS1115 potentiometer voltage test
2026-08-19 Add three-sensor I2C integration test
2026-08-20 Update README for RIP AFE hardware prototype
2026-08-20 Create initial RIP AFE schematic
    [RIP_AFE.SchDoc, SomniMate_RIP_AFE_Prototype.PrjPcb]
2026-08-20 Link landing page to RIP AFE verification
2026-08-20 Add final buffered RIP AFE schematic to README
2026-08-21 Document Rev A 3V3 AFE supply-filter simulation
2026-08-21 RIP_AFE shematic, LTSpice Plots and PI filter plots added
    [RIP_AFE.SchDoc, SomniMate_RIP_AFE_Prototype.PrjPcb]
2026-08-21 Complete Rev A RIP AFE schematic and design outputs
    [RIP_AFE.SchDoc, SomniMate_RIP_AFE_Prototype.PrjPcb]
2026-08-21 Update Rev A schematic and connected-system status
2026-08-21 Document completed Rev A schematic and supply filter
